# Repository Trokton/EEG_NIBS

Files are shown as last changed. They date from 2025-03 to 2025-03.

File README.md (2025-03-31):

# EEG_NIBS

🧠 Closed-Loop EEG & 4-Channel tACS/tDCS Neurostimulation System

Welcome to the documentation for a fully open-source, closed-loop EEG-integrated neurostimulation system, built entirely from scratch.

This repository contains the hardware designs, parts list, and firmware for a 4-channel tACS/tDCS stimulation system with real-time EEG integration, controlled via Python and Arduino Nano.

⸻

🧩 Project Overview

This system was developed to explore adaptive brain stimulation — modulating electrical currents based on real-time brain states, cognitive performance, or reinforcement learning algorithms.

Key Components:
	•	🧠 EEG Recording Module
	•	⚡ 4-Channel tDCS/tACS Stimulation Hardware
	•	🔁 Closed-Loop Python Control System
	•	🖥️ Arduino-based DAC current control
	•	🔐 Built-in Safety Features & Logging

The system is designed to serve researchers and developers interested in:
	•	Personalized neurostimulation
	•	Cognitive enhancement
	•	Reinforcement learning in neuroscience
	•	Brain-computer interfaces (BCIs)
	•	DIY neuroscience and open science hardware

⸻

🎯 Purpose

To provide a low-cost, flexible, and safe neurotechnology platform for:
	•	Closed-loop stimulation experiments
	•	Adaptive stimulation based on EEG/behavioral input
	•	Neuroscientific prototyping for brain state modulation
	•	Psychophysiological experiments

⸻

🛠️ Hardware Specifications

🔌 Stimulation Module (4-Channel tDCS/tACS)

Spec	Value/Feature
Channels	4 (individually addressable)
Max Current (per channel)	4 mA
Modulation Modes	tDCS, tACS (Sine, Square, Ramp, Custom)
Control Interface	Arduino Nano + DAC7311
Current Regulation	DAC-controlled + precision resistors
Voltage Reference	REF5050 or ADR5041 (5.0V)
Safety Features	Emergency analog cut-off, max current limit, resistance monitoring
Program Modes	5 fixed presets (2 x tDCS, 3 x tACS)
Control UI	1.3” OLED + 4 Buttons (Program, Start/Stop, ±Current)
Power Supply	Lab power (battery optional)

⸻

🧠 EEG Integration
	•	Interface for real-time EEG signal acquisition (designed for compatibility with OpenBCI or DIY amplifier)
	•	Real-time data streaming to Python
	•	Used to compute state, reward, and adaptation signals
	•	Clean switching logic to avoid interference during stimulation
	•	Log-based and adaptive session management

⸻

🧰 Bill of Materials (BoM)

(Full parts list available in parts_catalog.xlsx)

Example components:
	•	Arduino Nano (x4)
	•	DAC7311IDCKR (x2)
	•	TLC2252 Op-Amps (x4)
	•	REF5050 / ADR5041 Voltage Reference
	•	86.6Ω, 1.2kΩ, 2.2kΩ precision resistors
	•	1µF MLCC capacitors
	•	L78L05 voltage regulator
	•	SI8630BD Digital Isolator
	•	FMMT734/634 Darlington Transistors
	•	OLED 1.3” Display
	•	Tactile Buttons (x4)
	•	Toggle/Emergency Switch
	•	XL6009 Boost Converter

⸻

💻 Software / Firmware
	•	Arduino Sketches: arduino_code/
	•	Python Control Scripts (planned): python_control/
	•	EEG Integration & Analysis: eeg_pipeline/
	•	Safety & Log Scripts: logs/

⸻

🔄 Closed-Loop Flow
	1.	Cognitive Task → EEG + Task Performance Monitoring
	2.	Python Agent → Define State
	3.	RL Algorithm → Select Stimulation Protocol (Action)
	4.	Arduino Executes Program via DAC
	5.	EEG Feedback → Reward + Adaptation

⸻

📷 Visuals

PCB Layout, 3D Case Design, and Build Photos are included in assets/.

⸻

⚠️ Safety Notes
	•	Always monitor electrode resistance.
	•	Do not exceed 4 mA/channel.
	•	Use ramp-up/ramp-down transitions.
	•	Test with resistive dummy loads before skin contact.

⸻

👤 Author

Developed by Michael Roehrig, psychologist & AI enthusiast, diving into DIY neurotech to build accessible and intelligent brain interfaces.

Inspired by the incredible work of Prof. Roi Cohen Kadosh and open science communities.

⸻

📩 Contact & Collaboration

Interested in collaboration, replication, or feedback? Let’s connect via LinkedIn or GitHub issues!

⸻

📜 License

Open-source for research and educational use. Use responsibly. Not intended for clinical/medical use.

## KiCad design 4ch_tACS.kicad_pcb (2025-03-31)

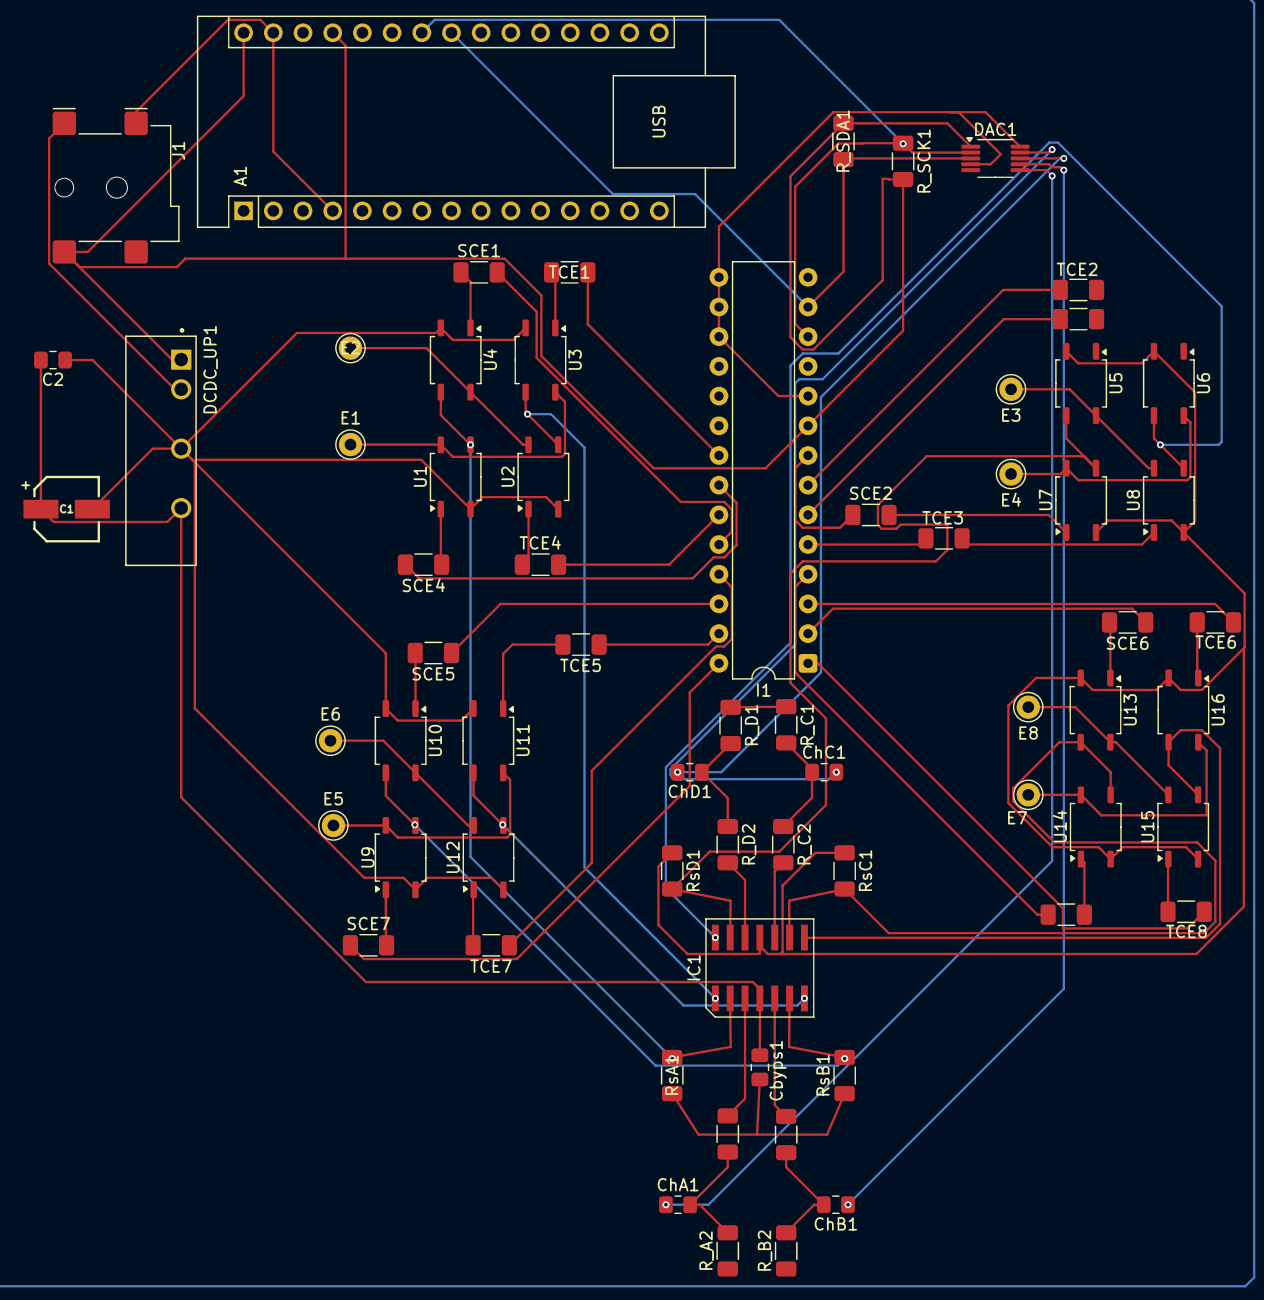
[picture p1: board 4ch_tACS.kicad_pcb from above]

Board: 2 copper layers, 67 parts (0 on the bottom side), 66 nets.

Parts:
A1: Arduino_Nano_v3.x; Arduino_Nano
C1: 10uF; WCAP-AS5H_5X5.5_DXL_
C2: 0.1 uF; C_0805_2012Metric_Pad1.18x1.45mm_HandSolder
Cbyps1: 0.1 uF; C_0805_2012Metric_Pad1.18x1.45mm_HandSolder
ChA1: 10 uF; C_0805_2012Metric_Pad1.18x1.45mm_HandSolder
ChB1: 10 uF; C_0805_2012Metric_Pad1.18x1.45mm_HandSolder
ChC1: 10 uF; C_0805_2012Metric_Pad1.18x1.45mm_HandSolder
ChD1: 10 uF; C_0805_2012Metric_Pad1.18x1.45mm_HandSolder
DAC1: MCP4728; MSOP-10_3x3mm_P0.5mm
DCDC_UP1: RE-0524S; CONV_RE-0524S
E1: Stim1; Pin_D1.0mm_L10.0mm
E2: Stim2; Pin_D1.0mm_L10.0mm
E3: Stim7; Pin_D1.0mm_L10.0mm
E4: Stim8; Pin_D1.0mm_L10.0mm
E5: Stim4; Pin_D1.0mm_L10.0mm
E6: Stim3; Pin_D1.0mm_L10.0mm
E7: Stim6; Pin_D1.0mm_L10.0mm
E8: Stim5; Pin_D1.0mm_L10.0mm
I1: MCP23017_SP; DIP-28_W7.62mm
IC1: OPA1664AIDR; SOIC127P600X175-14N
J1: Barrel_Jack; BarrelJack_Wuerth_694106106102_2.0x5.5mm
R_A1: 1k; R_1206_3216Metric_Pad1.30x1.75mm_HandSolder
R_A2: 100k; R_1206_3216Metric_Pad1.30x1.75mm_HandSolder
R_B1: 1k; R_1206_3216Metric_Pad1.30x1.75mm_HandSolder
R_B2: 100k; R_1206_3216Metric_Pad1.30x1.75mm_HandSolder
R_C1: 100k; R_1206_3216Metric_Pad1.30x1.75mm_HandSolder
R_C2: 1k; R_1206_3216Metric_Pad1.30x1.75mm_HandSolder
R_D1: 100k; R_1206_3216Metric_Pad1.30x1.75mm_HandSolder
R_D2: 1k; R_1206_3216Metric_Pad1.30x1.75mm_HandSolder
R_SCK1: 4.7k; R_1206_3216Metric_Pad1.30x1.75mm_HandSolder
R_SDA1: 4.7k; R_1206_3216Metric_Pad1.30x1.75mm_HandSolder
RsA1: 1.2k; R_1206_3216Metric_Pad1.30x1.75mm_HandSolder
RsB1: 1.2k; R_1206_3216Metric_Pad1.30x1.75mm_HandSolder
RsC1: 1.2k; R_1206_3216Metric_Pad1.30x1.75mm_HandSolder
RsD1: 1.2k; R_1206_3216Metric_Pad1.30x1.75mm_HandSolder
SCE1, SCE2, SCE3, SCE4, SCE5, SCE6, SCE7, SCE8: 470; R_1206_3216Metric_Pad1.30x1.75mm_HandSolder
TCE1, TCE2, TCE3, TCE4, TCE5, TCE6, TCE7, TCE8: 470; R_1206_3216Metric_Pad1.30x1.75mm_HandSolder
U1: SE1; SOP-4_3.8x4.1mm_P2.54mm
U2: TE2; SOP-4_3.8x4.1mm_P2.54mm
U3: TE1; SOP-4_3.8x4.1mm_P2.54mm
U4: SE2; SOP-4_3.8x4.1mm_P2.54mm
U5: SE7; SOP-4_3.8x4.1mm_P2.54mm
U6: TE8; SOP-4_3.8x4.1mm_P2.54mm
U7: SE8; SOP-4_3.8x4.1mm_P2.54mm
U8: TE7; SOP-4_3.8x4.1mm_P2.54mm
U9: SE4; SOP-4_3.8x4.1mm_P2.54mm
U10: SE3; SOP-4_3.8x4.1mm_P2.54mm
U11: TE4; SOP-4_3.8x4.1mm_P2.54mm
U12: TE3; SOP-4_3.8x4.1mm_P2.54mm
U13: SE5; SOP-4_3.8x4.1mm_P2.54mm
U14: SE6; SOP-4_3.8x4.1mm_P2.54mm
U15: TE5; SOP-4_3.8x4.1mm_P2.54mm
U16: TE6; SOP-4_3.8x4.1mm_P2.54mm

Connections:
/24V_GND: C1.2, C2.1, Cbyps1.2, DCDC_UP1.4 (-VOUT), IC1.11 (V-), RsA1.1, RsB1.1, RsC1.1, RsD1.1, U1.2, U2.2, U3.2, U4.2, U5.2, U6.2, U7.2, U8.2, U9.2, U10.2, U11.2, U12.2, U13.2, U14.2, U15.2, U16.2
/+5V: A1.27 (+5V), A1.30 (VIN), DAC1.1 (VDD), DCDC_UP1.1 (+VIN), I1.9 (VDD), J1.2, R_SCK1.2, R_SDA1.1
/+24V: C1.1, C2.2, Cbyps1.1, DCDC_UP1.6 (+VOUT), IC1.4 (V+)
/ChA_net: IC1.3 (+INA), R_A1.2
/ChB_net: IC1.5 (+INB), R_B1.2
/ChC_net: IC1.10 (+INC), R_C2.2
/ChD_net: IC1.12 (+IND), R_D2.2
/Sl_A: IC1.2 (-INA), RsA1.2, U1.3, U4.3
/Sl_B: IC1.6 (-INB), RsB1.2, U9.3, U10.3
/Sl_C: IC1.9 (-INC), RsC1.2, U13.3, U14.3
/Sl_D: IC1.13 (-IND), RsD1.2, U5.3, U7.3
unnamed: A1.23 (A4), DAC1.3 (SDA), I1.13 (SDA), R_SDA1.2
unnamed: A1.24 (A5), DAC1.2 (SCL), I1.12 (SCK), R_SCK1.1
unnamed: ChA1.2, R_A1.1, R_A2.2
unnamed: ChB1.2, R_B1.1, R_B2.2
unnamed: ChC1.1, R_C1.2, R_C2.1
unnamed: ChD1.1, R_D1.2, R_D2.1
unnamed: ChA1.1, DAC1.6 (VOUTA)
unnamed: ChB1.1, DAC1.7 (VOUTB)
unnamed: ChD1.2, DAC1.8 (VOUTC)
unnamed: ChC1.2, DAC1.9 (VOUTD)
unnamed: A1.4 (GND), A1.29 (GND), DAC1.4 (~LDAC), DAC1.10 (VSS), DCDC_UP1.2 (-VIN), I1.10 (VSS), I1.15 (A0), I1.16 (A1), I1.17 (A2), J1.1, R_A2.1, R_B2.1, R_C1.1, R_D1.1
unnamed: E1.1, U1.4, U3.4
unnamed: E2.E2, U2.4, U4.4
unnamed: E6.1, U10.4, U12.4
unnamed: E5.1, U9.4, U11.4
unnamed: E8.1, U13.4, U15.4
unnamed: E7.1, U14.4, U16.4
unnamed: E3.1, U5.4, U8.4
unnamed: E4.1, U6.4, U7.4
unnamed: I1.21 (GPA0), TCE1.2
unnamed: I1.22 (GPA1), SCE4.2
unnamed: I1.23 (GPA2), TCE4.2
unnamed: I1.24 (GPA3), SCE1.2
unnamed: I1.25 (GPA4), TCE7.1
unnamed: I1.26 (GPA5), SCE5.1
unnamed: I1.27 (GPA6), TCE5.1
unnamed: I1.28 (GPA7), SCE7.1
unnamed: I1.1 (GPB0), TCE8.1
unnamed: I1.2 (GPB1), SCE6.1
unnamed: I1.3 (GPB2), TCE6.1
unnamed: I1.4 (GPB3), SCE8.1
unnamed: I1.5 (GPB4), TCE3.1
unnamed: I1.6 (GPB5), SCE3.1
unnamed: I1.7 (GPB6), TCE2.1
unnamed: I1.8 (GPB7), SCE2.1
unnamed: IC1.1 (OUTA), U2.3, U3.3
unnamed: IC1.7 (OUTB), U11.3, U12.3
unnamed: IC1.8 (OUTC), U15.3, U16.3
unnamed: IC1.14 (OUTD), U6.3, U8.3
unnamed: SCE6.2, U13.1
unnamed: SCE8.2, U14.1
unnamed: SCE3.2, U5.1
unnamed: SCE2.2, U7.1
unnamed: SCE4.1, U1.1
unnamed: SCE1.1, U4.1
unnamed: SCE5.2, U10.1
unnamed: SCE7.2, U9.1
unnamed: TCE8.2, U15.1
unnamed: TCE6.2, U16.1
unnamed: TCE3.2, U8.1
unnamed: TCE2.2, U6.1
unnamed: TCE1.1, U3.1
unnamed: TCE4.1, U2.1
unnamed: TCE7.2, U12.1
unnamed: TCE5.2, U11.1

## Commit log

2025-03-04 Data template
    [eeg_data.csv]
2025-03-04 Threading mode implemented
2025-03-31 Hardware layout of the NIBS circuit
    4-Channel tACS/tDCS device with arbitrary assignment of each electrode as channels anode or cathode
    [4ch_tACS.kicad_pcb, 4ch_tACS.kicad_sch]
